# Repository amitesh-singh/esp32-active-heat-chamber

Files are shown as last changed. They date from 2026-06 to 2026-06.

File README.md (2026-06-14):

# ESP32 Active Heat Chamber

An ESP32-C3-based active heat chamber controller for 3D printers, designed to integrate with [Klipper](https://www.klipper3d.org/) via a REST API. It drives a PTC ceramic heater and a 5015 blower fan using closed-loop PID temperature control, and exposes an HTTP API that Klipper macros call directly via `gcode_shell_command`.

## Table of Contents

- [Features](#features)
- [Hardware](#hardware)
  - [Schematic](#schematic)
  - [Assembly](#assembly)
  - [Bill of Materials](#bill-of-materials)
  - [Pin Assignments](#pin-assignments)
- [Software Architecture](#software-architecture)
- [Dependencies](#dependencies)
- [Getting Started](#getting-started)
  - [Compile](#compile)
  - [Upload via USB](#upload-via-usb)
  - [OTA Updates](#ota-updates)
- [Configuration](#configuration)
- [REST API](#rest-api)
- [Klipper Integration](#klipper-integration) *(work in progress)*
- [License](#license)

---

## Features

- **PID temperature control** — closed-loop heater control with anti-windup
- **Time-proportional heater output** — SSR-compatible PWM-style on/off cycling (2 s cycle)
- **5015 blower fan control** — 25 kHz PWM via ESP32-C3 LEDC peripheral
- **SHT30 temperature + humidity sensor** — high-accuracy I²C sensor
- **OLED status display** — 128×64 SSD1306 showing temp, humidity, setpoint, fan, and PID power bar
- **HTTP REST API** — control heater, fan, and setpoint from any client
- **Klipper integration** *(work in progress)* — `klipper_chamber.cfg` with GCode macros
- **Automatic OTA firmware updates** — checks a self-hosted HTTPS server on boot and updates if a newer version is available
- **WiFiManager captive portal** — no hardcoded credentials; connect to the `HeaterChamber-XXXX` AP on first boot to configure WiFi
- **MCU temperature monitoring** — uses the ESP32-C3 internal temperature sensor
- **Safety limits** — hard cut-off at 65 °C and automatic recovery when temperature overshoots setpoint by ≥ 5 °C

---

## Hardware

### Schematic

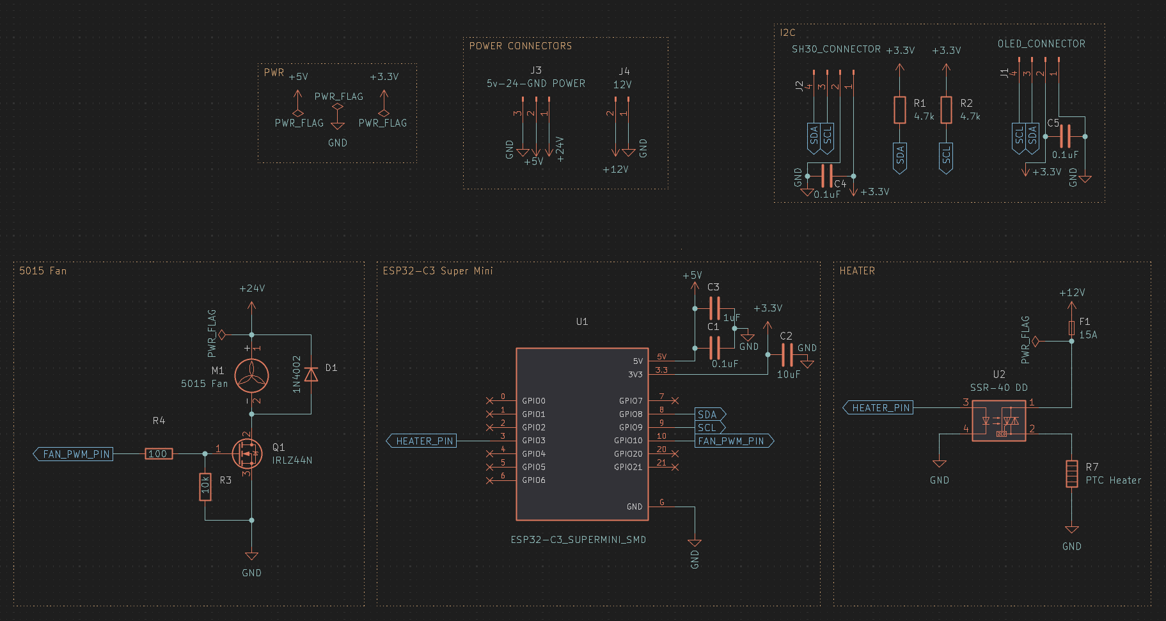
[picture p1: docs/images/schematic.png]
Schematic


> Place the exported schematic PNG at `docs/images/schematic.png`.

The circuit consists of four blocks:

| Block | Description |
|---|---|
| **ESP32-C3 Super Mini** | Main MCU — runs the HTTP server, PID loop, and OTA |
| **Heater driver** | SSR-40 DD solid-state relay switches 12 V to the PTC heater through a 15 A fuse |
| **Fan driver** | IRLZ44N logic-level MOSFET with 100 Ω gate resistor and 10 kΩ pull-down drives the 24 V 5015 fan |
| **I²C peripherals** | SHT30 sensor and SSD1306 OLED share the I²C bus with 4.7 kΩ pull-ups |

### Assembly

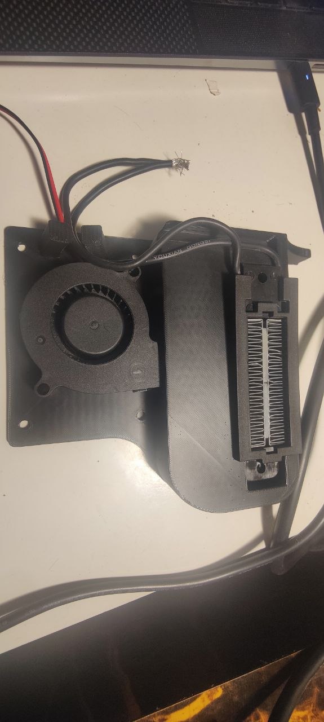
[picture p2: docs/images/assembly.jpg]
Assembly — blower fan and PTC heater holder


> Place the assembly photo at `docs/images/assembly.jpg`.

The 3D-printed mount (STL/STEP files in `enclosures/fan-ptcheater-holder/`) integrates a **5015 radial blower fan** and a **PTC ceramic heater** side-by-side. Airflow is forced through the PTC element and into the printer enclosure.

---

### Bill of Materials

| # | Component | Value / Part | Qty | Notes |
|---|---|---|---|---|
| U1 | ESP32-C3 Super Mini | — | 1 | SMD or through-hole module |
| U2 | Solid-state relay | SSR-40 DD | 1 | 12 V load side, 3.3 V control |
| Q1 | N-channel MOSFET | IRLZ44N | 1 | Logic-level gate, TO-220 |
| M1 | Blower fan | 5015, 24 V | 1 | ~1.5 A rated |
| — | PTC ceramic heater | 12 V, ~100 W | 1 | R7 in schematic |
| F1 | Fuse | 15 A | 1 | Inline on 12 V rail |
| D1 | Flyback diode | 1N4002 | 1 | Across fan motor |
| R1, R2 | I²C pull-up | 4.7 kΩ | 2 | SDA/SCL lines |
| R3 | Gate pull-down | 10 kΩ | 1 | MOSFET gate |
| R4 | Gate resistor | 100 Ω | 1 | MOSFET gate series |
| C1 | Bulk cap | 1 µF | 1 | 5 V rail |
| C2 | Bypass cap | 10 µF | 1 | 3.3 V rail |
| C3 | Bypass cap | 0.1 µF | 1 | 5 V rail |
| C4 | Bypass cap | 0.1 µF | 1 | SHT30 VDD |
| C5 | Bypass cap | 0.1 µF | 1 | OLED VDD |
| J2 | SHT30 connector | 4-pin SH1.0 | 1 | VDD, GND, SDA, SCL |
| J1 | OLED connector | 4-pin | 1 | VCC, GND, SCL, SDA |
| J3 | Power connector | 3-pin (5 V, 24 V, GND) | 1 | — |
| J4 | Power connector | 2-pin (12 V, GND) | 1 | — |
| — | SHT30 sensor module | — | 1 | I²C address 0x44 |
| — | SSD1306 OLED | 128×64 | 1 | I²C address 0x3C |

### Pin Assignments

| GPIO | Function |
|---|---|
| GPIO 3 | Heater SSR control (on/off) |
| GPIO 10 | Fan PWM (25 kHz LEDC) |
| GPIO 8 | I²C SDA (SHT30 + OLED) |
| GPIO 9 | I²C SCL (SHT30 + OLED) |

---

## Software Architecture

```
active_heat_chamber_esp32.ino   Main sketch: WiFi, HTTP server, sensor loop, PID loop
config.h                        Compile-time constants (pins, PID gains, safety limits)
heater_controller.h             Time-proportional on/off heater class
pid_controller.h                Generic PID with anti-windup and output clamping
oled_display.h                  SSD1306 status display
automatic_ota.h                 HTTPS OTA update client
```

The main loop runs three independent timed tasks:

| Task | Interval | Action |
|---|---|---|
| Sensor read | 1 s | Read SHT30 temp + humidity, run safety checks |
| PID update | 500 ms | Compute PID output, apply to `heater_controller` and fan |
| OLED refresh | 1 s | Redraw display |

---

## Dependencies

Install these via the Arduino Library Manager or `arduino-cli lib install`:

| Library | Purpose |
|---|---|
| `WiFiManager` | Captive-portal WiFi provisioning |
| `Adafruit GFX Library` | OLED graphics primitives |
| `Adafruit SSD1306` | SSD1306 OLED driver |
| `SensirionI2cSht3x` | SHT30/SHT31 sensor driver |
| `ArduinoJson` | JSON parsing for OTA manifest |
| `ElegantOTA` *(optional)* | Web-based OTA (disabled by default — uncomment `#define WEB_OTA`) |

Board package: **esp32 by Espressif** — install via Board Manager (`https://raw.githubusercontent.com/espressif/arduino-esp32/gh-pages/package_esp32_index.json`).

---

## Getting Started

### Compile

```bash
./build.sh
```

This calls `arduino-cli` targeting the **ESP32-C3** with CDC-on-boot enabled and the `min_spiffs` partition scheme:

```bash
arduino-cli compile -v \
  --fqbn esp32:esp32:esp32c3:CDCOnBoot=cdc,PartitionScheme=min_spiffs \
  --build-property "compiler.optimization_flags=-Os" \
  .
```

### Upload via USB

Connect the ESP32-C3 Super Mini over USB, then:

```bash
./upload.sh
```

This runs:

```bash
arduino-cli upload \
  -p /dev/ttyACM0 \
  --fqbn esp32:esp32:esp32c3:CDCOnBoot=cdc,PartitionScheme=min_spiffs \
  .
```

> Adjust the port (`-p /dev/ttyACM0`) if your device appears on a different path (e.g. `/dev/ttyUSB0`).

### OTA Updates

Firmware updates are served over HTTPS from a local server. The ESP32 checks `UPDATE_JSON_URL` (defined in `active_heat_chamber_esp32.ino`) on every boot.

#### 1. Generate TLS certificates

```bash
cd ota_server
./create_keys.sh   # creates cert.pem and key.pem (self-signed, valid 365 days)
```

#### 2. Build and package firmware

```bash
./build.sh         # compile the sketch
./flash.sh         # copies the .bin to ota_server/firmware.bin and writes firmware.json
```

`flash.sh` reads `FW_VERSION` from `config.h` and generates:

```json
{
  "version": "0.1.1",
  "firmware": "https://192.168.1.13/firmware.bin"
}
```

#### 3. Start the HTTPS server

```bash
cd ota_server
sudo python3 https_run.py   # serves on port 443
```

> For plain HTTP testing on port 80: `./http_run.sh`

Update `UPDATE_JSON_URL` in `active_heat_chamber_esp32.ino` to point at your server's IP.

---

## Configuration

All compile-time settings live in `config.h`:

```cpp
#define FW_VERSION       "0.1.1"

// GPIO
#define HEATER_PIN       3      // SSR control
#define FAN_PWM_PIN      10     // LEDC PWM output

// Fan PWM
#define FAN_FREQ_HZ      25000  // 25 kHz
#define FAN_RESOLUTION   8      // 0–255

// Safety
#define MAX_TEMP_C       65.0f  // Hard cut-off temperature
#define DEFAULT_TARGET   50.0f  // Default setpoint on boot
#define HEATER_CYCLE_MS  2000   // Time-proportional cycle period (ms)

// PID gains
#define PID_KP           0.08f
#define PID_KI           0.015f
#define PID_KD           0.005f

// I²C
#define I2C_SDA          8
#define I2C_SCL          9
```

Tune `PID_KP`, `PID_KI`, `PID_KD` to match your heater and fan combination.

---

## REST API

The HTTP server listens on port **80**. All responses are JSON.

| Method | Endpoint | Parameters | Description |
|---|---|---|---|
| `GET` | `/status` | — | Returns full chamber status |
| `POST` | `/heater` | `state=on\|off` | Enable or disable the heater |
| `POST` | `/temp` | `target=<20–80>` | Set target temperature (°C) |
| `POST` | `/fan` | `speed=<0–255>` | Override fan speed |

### `/status` response

```json
{
  "temp": 47.32,
  "humid": 28.10,
  "setpoint": 50.0,
  "heater": true,
  "fan": 180,
  "pid_output": 0.612,
  "safety_tripped": false,
  "sensor_fault": false,
  "mcu_temp": 38.50,
  "fw_ver": "0.1.1",
  "ip": "192.168.1.20"
}
```

### Examples

```bash
# Turn heater on
curl -X POST "http://192.168.1.20/heater?state=on"

# Set target to 60 °C
curl -X POST "http://192.168.1.20/temp?target=60"

# Set fan to 50 % (128/255)
curl -X POST "http://192.168.1.20/fan?speed=128"

# Read status
curl "http://192.168.1.20/status"
```

### Web UI

The ESP32 also serves a built-in web dashboard at `http://<ESP32_IP>/`. It auto-refreshes every second and provides full control without any external tooling.

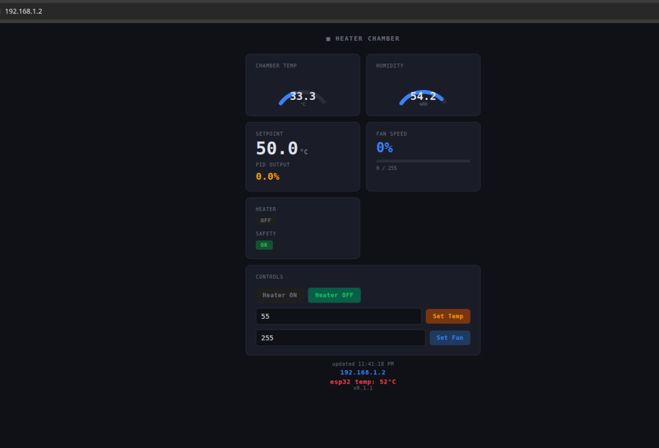
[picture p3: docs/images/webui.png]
Web UI — Heater Chamber dashboard


> Place the web UI screenshot at `docs/images/webui.png`.

The dashboard shows:
- **Chamber Temp** and **Humidity** gauges
- **Setpoint** and current **PID output**
- **Fan speed** bar and value
- **Heater** state (ON/OFF) and **Safety** status
- Controls to toggle the heater, set target temperature, and set fan speed
- Footer showing last-update time, IP address, MCU temperature, and firmware version

---

## Klipper Integration

> **Work in progress** — the Klipper integration (`klipper_chamber.cfg` and `chamber_control.sh`) is functional but still being refined. Use the [REST API](#rest-api) or the [Web UI](#web-ui) for direct control in the meantime.

### 1. Install the `gcode_shell_command` plugin

```bash
cd ~/klipper
wget -O klippy/extras/gcode_shell_command.py \
  https://raw.githubusercontent.com/th33xitus/kiauh/master/resources/gcode_shell_command.py
```

### 2. Install the control script

```bash
sudo cp chamber_control.sh /usr/local/bin/chamber_control.sh
sudo chmod +x /usr/local/bin/chamber_control.sh
```

Edit `ESP32_IP` at the top of `chamber_control.sh` to match your ESP32's IP address (assign a static DHCP lease in your router for reliability).

### 3. Include the config

Add to `printer.cfg`:

```ini
[include klipper_chamber.cfg]
```

### Available GCode macros

| Macro | Example | Description |
|---|---|---|
| `CHAMBER_ON` | `CHAMBER_ON TEMP=60` | Enable heater and set target temperature |
| `CHAMBER_OFF` | `CHAMBER_OFF` | Disable heater and fan |
| `CHAMBER_TEMP` | `CHAMBER_TEMP TARGET=65` | Change setpoint while running |
| `CHAMBER_FAN` | `CHAMBER_FAN SPEED=180` | Set fan speed (0–255) |
| `CHAMBER_STATUS` | `CHAMBER_STATUS` | Print current status to console |
| `CHAMBER_WAIT` | `CHAMBER_WAIT TEMP=58` | Block until chamber reaches temperature |

### Typical print-start sequence

```gcode
CHAMBER_ON TEMP=60          ; start heating
CHAMBER_WAIT TEMP=55        ; wait until warm enough
; ... home, load filament, start print ...
CHAMBER_OFF                 ; cool down after print
```

---

## License

[LICENSE](LICENSE)

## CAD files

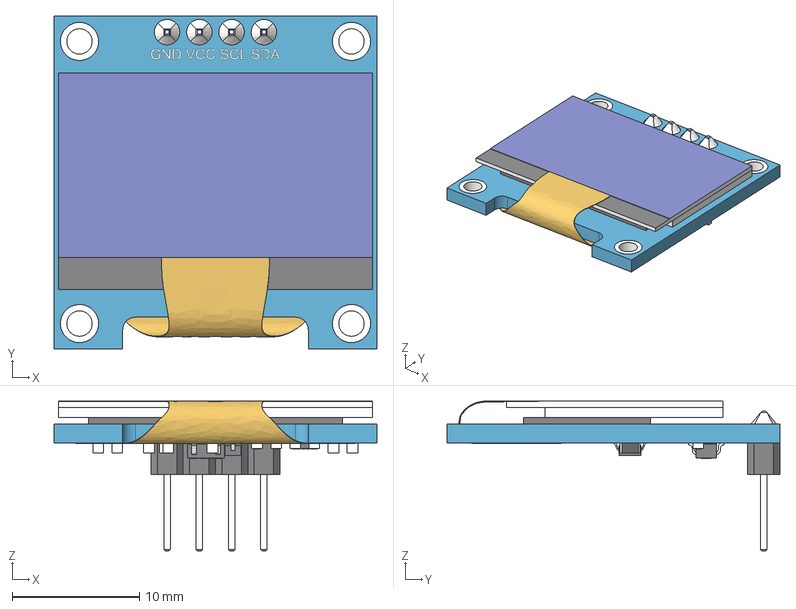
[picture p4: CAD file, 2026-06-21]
enclosures/esp32c3-oled/SSD1306_OLED_Display(128x64).step
25.4 x 26.2 x 11.8 mm
board
screen
pin_header
soldering
smd_capacitor
smd_capacitor (1)
914_smd_resistor
472_smd_resistor x 3
t4_smd_diode
smd_capacitor (2)
smd_capacitor (3)
smd_capacitor (4)
smd_capacitor (5)
smd_capacitor (6)
472_smd_resistor (1)
SOT-23_XC6206 v3
smd_capacitor (7)
flat_cable

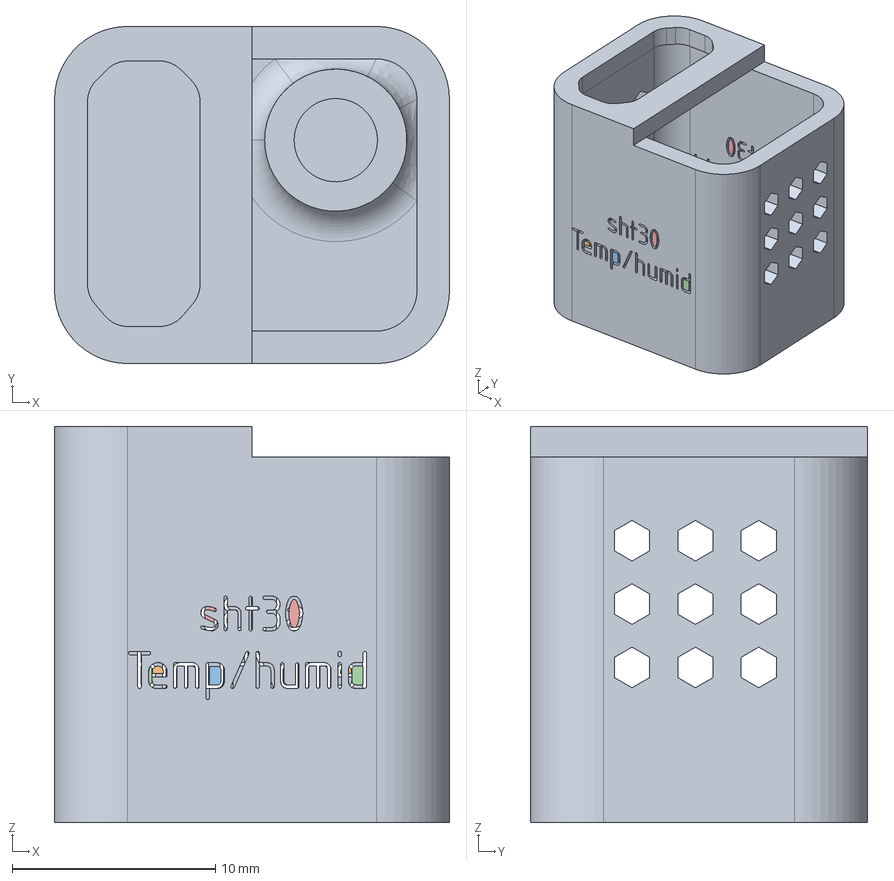
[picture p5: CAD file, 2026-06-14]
enclosures/sht30/sht30-sht30cover.step
19.5 x 16.6 x 19.5 mm

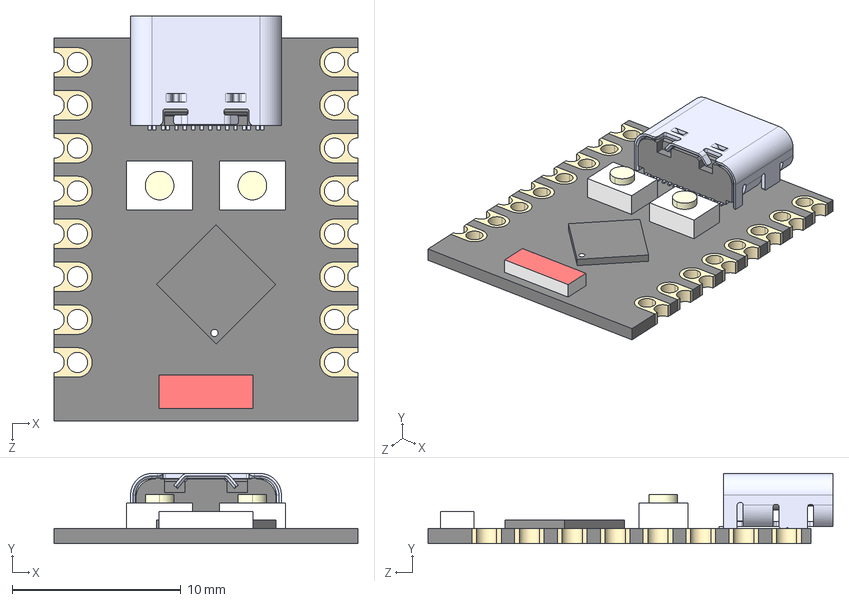
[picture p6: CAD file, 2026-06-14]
schematics/heater/ESP32-C3_SUPERMINI_SMD.step
18.0 x 4.16 x 24.0 mm
Board c3mini
USB C
components (other)^ESP32-C3 SuperMini

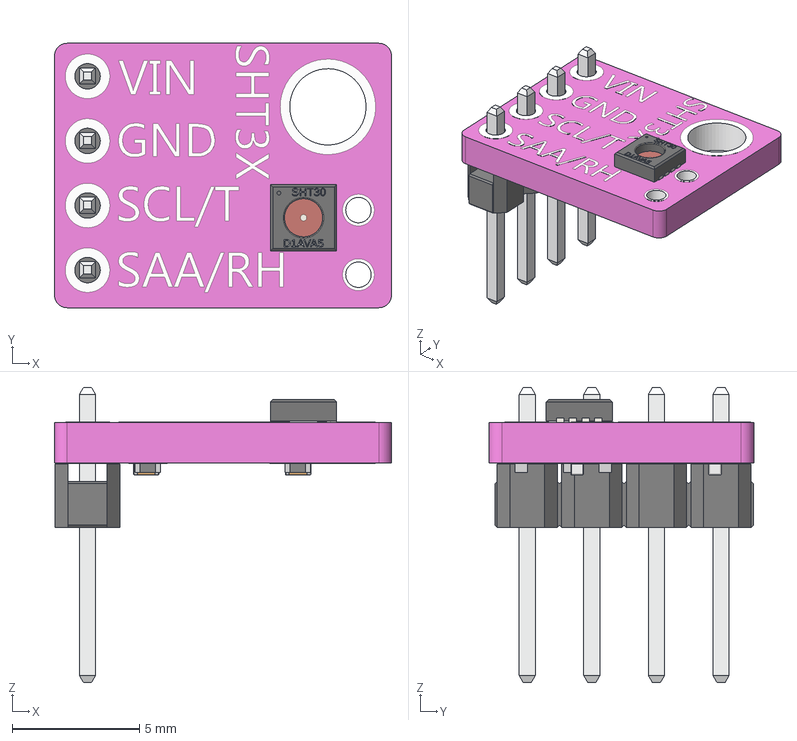
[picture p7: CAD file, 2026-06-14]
enclosures/sht30/SHT30-Purple Straight Pins.step
13.2 x 10.4 x 11.6 mm
PCB
Resistor 0402 x 3
pin x 4

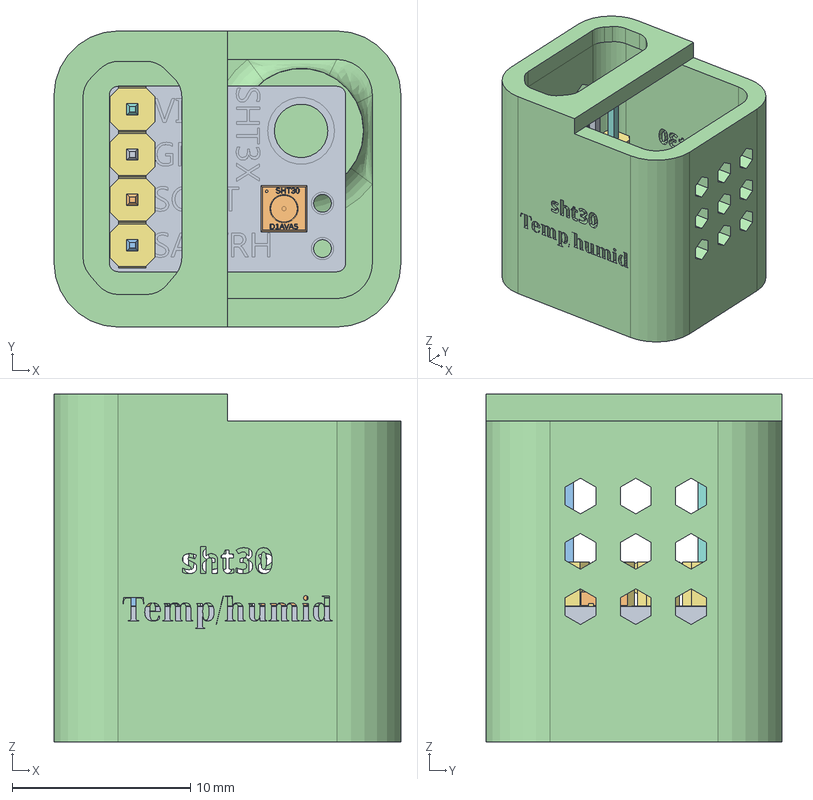
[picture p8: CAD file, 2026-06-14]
enclosures/sht30/sht30.FCStd
19.5 x 16.6 x 19.5 mm
PCB
Resistor 0402 v2
Resistor 0402 v001
Resistor 0402 v002
Resistor 0402 v003
Resistor 0402 v004
Resistor 0402 v005
Resistor 0402 v006
Resistor 0402 v008
Resistor 0402 v009
Resistor 0402 v010
Resistor 0402 v011
Resistor 0402 v012
Resistor 0402 v013
Resistor 0402 v014
Resistor 0402 v016
Resistor 0402 v017
Resistor 0402 v018
Resistor 0402 v019
Resistor 0402 v020
Resistor 0402 v021
Resistor 0402 v022
pin
pin001
pin002
pin003
sht30cover

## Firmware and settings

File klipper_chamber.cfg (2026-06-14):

# klipper_chamber.cfg
# Heater chamber control via gcode_shell_command → ESP32 REST API
#
# Prerequisites:
#   1. Install gcode_shell_command plugin:
#      cd ~/klipper
#      wget -O ~/klipper/klippy/extras/gcode_shell_command.py \
#        https://raw.githubusercontent.com/th33xitus/kiauh/master/resources/gcode_shell_command.py
#
#   2. Install and configure the shell script:
#      sudo cp chamber_control.sh /usr/local/bin/chamber_control.sh
#      sudo chmod +x /usr/local/bin/chamber_control.sh
#      # Edit ESP32_IP in the script to match your ESP32's IP
#
#   3. Include this file in printer.cfg:
#      [include klipper_chamber.cfg]
#
# Usage in GCode / macros:
#   CHAMBER_ON TEMP=60
#   CHAMBER_OFF
#   CHAMBER_TEMP TARGET=65
#   CHAMBER_FAN SPEED=180
#   CHAMBER_STATUS
#   CHAMBER_WAIT TEMP=58        ; blocks until chamber reaches temp


# ── Shell command definitions ─────────────────────────────────────────────────

[gcode_shell_command chamber_heater_on]
command: /usr/local/bin/chamber_control.sh heater on
timeout: 8
verbose: True

[gcode_shell_command chamber_heater_off]
command: /usr/local/bin/chamber_control.sh heater off
timeout: 8
verbose: True

[gcode_shell_command chamber_set_temp]
command: /usr/local/bin/chamber_control.sh temp
timeout: 8
verbose: True

[gcode_shell_command chamber_set_fan]
command: /usr/local/bin/chamber_control.sh fan
timeout: 8
verbose: True

[gcode_shell_command chamber_get_status]
command: /usr/local/bin/chamber_control.sh status
timeout: 8
verbose: True


# ── GCode Macros ──────────────────────────────────────────────────────────────

# CHAMBER_ON TEMP=60
# Turn heater on and set target temperature (default 60°C)
[gcode_macro CHAMBER_ON]
description: Turn on heater chamber and set target temperature
gcode:
    {% set target = params.TEMP|default(60)|float %}
    M118 Chamber: setting target to {target}C
    RUN_SHELL_COMMAND CMD=chamber_set_temp PARAMS="{target}"
    RUN_SHELL_COMMAND CMD=chamber_heater_on
    M118 Chamber: heater ON, target={target}C


# CHAMBER_OFF
# Turn off heater and fan
[gcode_macro CHAMBER_OFF]
description: Turn off heater chamber
gcode:
    M118 Chamber: turning off
    RUN_SHELL_COMMAND CMD=chamber_heater_off
    M118 Chamber: heater OFF


# CHAMBER_TEMP TARGET=65
# Update setpoint without toggling heater state
[gcode_macro CHAMBER_TEMP]
description: Set chamber target temperature
gcode:
    {% set target = params.TARGET|default(60)|float %}
    M118 Chamber: setpoint → {target}C
    RUN_SHELL_COMMAND CMD=chamber_set_temp PARAMS="{target}"


# CHAMBER_FAN SPEED=180
# Manually override fan speed (0-255). Heater auto-fan resumes on next PID cycle.
[gcode_macro CHAMBER_FAN]
description: Set chamber fan speed (0-255)
gcode:
    {% set speed = params.SPEED|default(128)|int %}
    M118 Chamber: fan → {speed}
    RUN_SHELL_COMMAND CMD=chamber_set_fan PARAMS="{speed}"


# CHAMBER_STATUS
# Print current chamber state to console
[gcode_macro CHAMBER_STATUS]
description: Query chamber temperature and state
gcode:
    M118 Chamber: querying status...
    RUN_SHELL_COMMAND CMD=chamber_get_status


# CHAMBER_WAIT TEMP=58
# Poll chamber until temperature reaches target (blocking, with timeout)
# Call BEFORE starting a print that needs a warm chamber.
[gcode_macro CHAMBER_WAIT]
description: Wait for chamber to reach target temperature
variable_poll_interval: 10    ; seconds between status checks
variable_max_wait: 1200       ; max wait time in seconds (20 min)
gcode:
    {% set target = params.TEMP|default(55)|float %}
    {% set tolerance = params.TOLERANCE|default(2)|float %}
    M118 Chamber: waiting for {target}C (±{tolerance}C)...
    RUN_SHELL_COMMAND CMD=chamber_set_temp PARAMS="{target}"
    RUN_SHELL_COMMAND CMD=chamber_heater_on

    # Klipper's TEMPERATURE_WAIT can't query external sensors directly,
    # so we use a timed loop with shell status checks.
    # For a cleaner approach, expose the ESP32 temp as a dummy sensor (see note below).
    {% set ns = namespace(elapsed=0, done=false) %}
    {% for i in range((max_wait // poll_interval)|int) %}
        {% if not ns.done %}
            G4 P{poll_interval * 1000}
            RUN_SHELL_COMMAND CMD=chamber_get_status
            M118 Chamber: waiting... ({(i+1)*poll_interval}s elapsed)
        {% endif %}
    {% endfor %}
    M118 Chamber: wait complete (or timed out after {max_wait}s)

# ── Print start / end integration ─────────────────────────────────────────────
# Add these calls to your existing START_PRINT / END_PRINT macros:
#
# [gcode_macro START_PRINT]
# gcode:
#     ...
#     CHAMBER_ON TEMP=60          # start heating
#     CHAMBER_WAIT TEMP=58        # wait before printing (optional)
#     ...
#
# [gcode_macro END_PRINT]
# gcode:
#     ...
#     CHAMBER_OFF                 # cut heater when done
#     ...
#
# ── Expose ESP32 temp as a Klipper sensor (optional but recommended) ──────────
# This lets TEMPERATURE_WAIT and the Mainsail/Fluidd dashboard see chamber temp.
# Requires a small Python sensor plugin or moonraker data_store — see:
# https://www.klipper3d.org/Config_Reference.html#temperature_sensor
#
# [temperature_sensor chamber]
# sensor_type: temperature_host   # placeholder; replace with custom plugin

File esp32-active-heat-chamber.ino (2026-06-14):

/**
 * chamber_server.ino
 * ESP32 HTTP REST server for Klipper-controlled heater chamber
 *
 * Endpoints:
 *   POST /heater?state=on|off
 *   POST /temp?target=50.0
 *   POST /fan?speed=0-255
 *   GET  /status   → JSON: temp, humid, setpoint, heater, fan, pid_output, safety_tripped, sensor_fault, mcu_temp, fw_ver, ip
 *
 */

#include <Arduino.h>
#include <WiFi.h>
#include <WebServer.h>
#include <Wire.h>
#include <WiFiManager.h>

#include "config.h"
#include "heater_controller.h"
#include "pid_controller.h"

#define DEBUG
//#define WEB_OTA
#ifdef WEB_OTA
#include <ElegantOTA.h>
#endif 

#include "oled_display.h"
display *d = nullptr;

#include "automatic_ota.h"

#include <SensirionI2cSht3x.h>
SensirionI2cSht3x sht30;

// ESP-IDF temperature sensor API
extern "C" {
  #include "driver/temperature_sensor.h"
}
temperature_sensor_handle_t temp_sensor = NULL;

void setup_mcu_temp()
{
  temperature_sensor_config_t temp_config = {
    .range_min = -10,  // Minimum expected temperature (°C)
    .range_max = 80    // Maximum expected temperature (°C)
  };

  // Install temperature sensor
  esp_err_t err = temperature_sensor_install(&temp_config, &temp_sensor);
  if (err != ESP_OK) {
    #ifdef DEBUG
    Serial.println("Failed to install temperature sensor");
    #endif
    return;
  }

  // Enable temperature sensor
  err = temperature_sensor_enable(temp_sensor);
  if (err != ESP_OK) {
    #ifdef DEBUG
    Serial.println("Failed to enable temperature sensor");
    #endif
    return;
  }
  #ifdef DEBUG
  Serial.println("Temperature sensor initialized\n");
  #endif
}

heater_controller  hc(HEATER_PIN, HEATER_CYCLE_MS);
pid_controller pid(PID_KP, PID_KI, PID_KD, 0.0f, 1.0f);
WebServer     server(80);
#ifdef WEB_OTA
WebServer ota_server(81);
#endif

//TODO: change it to github later
#define UPDATE_JSON_URL "https://192.168.1.13/firmware.json"

https_ota ota(
    FW_VERSION,
    UPDATE_JSON_URL,
    []() { if (d) d->ota_update_uptodate(); },
    []() { if (d) d->ota_update_install(); }
);

float   currentTemp     = 0.0f;
float   currentHumidity = 0.0f;
float   pidOutput     = 0.0f;
uint8_t fanSpeed      = 0;
bool    heaterEnabled = false;
bool    safetyTripped = false;
bool    sensorOk        = false;
bool    sensorFault     = false;
bool    highTempFault   = false;
bool    forceHeaterStopped = false;
float   mcu_temp = 0.0f;

uint32_t lastPid    = 0;
uint32_t lastSensor = 0;
uint32_t lastOled    = 0;

constexpr const auto HTTP_RESPONSE_200 = 200;
constexpr const auto HTTP_RESPONSE_400 = 400;

bool readSensor()
{
    float t, h;
    uint16_t err = sht30.measureSingleShot(REPEATABILITY_HIGH, false, t, h);
    if (err) {
      #ifdef DEBUG
        Serial.printf("[SHT30] Error: %d\r\n", err);
      #endif  
        sensorFault = true;
        return false;
    }
    sensorFault = false;
    currentTemp     = t;
    currentHumidity = h;
    return true;
}

void applyFanSpeed(uint8_t speed)
{
    fanSpeed = speed;
    ledcWrite(FAN_PWM_PIN, speed);
}

void checkSafety(float t)
{
    if (t >= MAX_TEMP_C || t < -50.0f) {
        hc.emergencyStop();
        applyFanSpeed(255);
        heaterEnabled = false;
        safetyTripped = true;
        #ifdef DEBUG
        Serial.printf("[SAFETY] Tripped at %.1f°C\n", t);
        #endif

    } else {
      //The currentTemp should not go more than 5C than the setTemp
      if (heaterEnabled and currentTemp > pid.getSetpoint() and (currentTemp - pid.getSetpoint()) >= 5) {
        applyFanSpeed(0);
        hc.emergencyStop();
        heaterEnabled = false;
        highTempFault = true;
        
        safetyTripped = true;
        #ifdef DEBUG
        Serial.printf("[SAFETY] currentTemp is higher than setTemp: %.2f : %.2f\r\n",
          currentTemp, pid.getSetpoint());
        #endif 
      }
    }

    if (sensorFault)  {
      hc.emergencyStop();
      applyFanSpeed(0);
      heaterEnabled = false;
      safetyTripped = true;
      #ifdef DEBUG
      Serial.println("[SAFETY] Tripped due to sensor fault");
      #endif
    } else {
      //if the sensor is ok, we can clear the fault;
      //heaterEnabled = true;
      if (!highTempFault)
        safetyTripped = false;
    }
    
    //only clear the fault if externally heater is not stopped
    if (!forceHeaterStopped and highTempFault) {
      //wait for the currentTemp to go down; to restart everything.
      if (currentTemp < pid.getSetpoint() and (pid.getSetpoint() - currentTemp) >= 2) {
        //clear the fault;
        heaterEnabled = true;
        hc.enable();
        pid.reset();
        highTempFault = false;
        safetyTripped = false;
        #ifdef DEBUG
        Serial.printf("[SAFETY] cleared the fault:\r\n");
        #endif
      }
    }
}

String statusJson()
{
    char buf[256];
    String ip = WiFi.localIP().toString();
    constexpr auto *t = "true";
    constexpr auto *f = "false";

    snprintf(buf, sizeof(buf),
        "{\"temp\":%.2f,\"humid\":%.2f,\"setpoint\":%.1f,\"heater\":%s,"
        "\"fan\":%d,\"pid_output\":%.3f,\"safety_tripped\":%s,"
        "\"sensor_fault\":%s,"
        "\"mcu_temp\":%.2f,"
        "\"fw_ver\":\"%s\","
        "\"ip\":\"%s\"}",
        currentTemp, currentHumidity, pid.getSetpoint(),
        heaterEnabled ? t : f,
        fanSpeed, pidOutput,
        safetyTripped ? t : f,
        sensorFault ? t : f,
        mcu_temp,
        FW_VERSION,
        ip.c_str());

    return String(buf);
}

// GET /status
void handleStatus()
{
    server.send(HTTP_RESPONSE_200, "application/json", statusJson());
}

// POST /heater?state=on|off
void handleHeater()
{
    if (!server.hasArg("state")) {
        server.send(HTTP_RESPONSE_400, "application/json", "{\"error\":\"missing state\"}"); return;
    }
    String state = server.arg("state");
    if (state == "on" && !safetyTripped) {
        forceHeaterStopped = false;
        heaterEnabled = true;
        hc.enable();
        pid.reset();
        #ifdef DEBUG
        Serial.println("[HTTP] Heater ON");
        #endif
    } else if (state == "off") {
        forceHeaterStopped = true;
        heaterEnabled = false;
        //we clear the hightemp fault too;
        highTempFault = false;
        safetyTripped = false;
        hc.disable();
        applyFanSpeed(0);
        pidOutput = 0;
        pid.reset();
        #ifdef DEBUG
        Serial.println("[HTTP] Heater OFF");
        #endif
    } else {
        server.send(HTTP_RESPONSE_400, "application/json", "{\"error\":\"invalid state\"}"); return;
    }
    server.send(HTTP_RESPONSE_200, "application/json", statusJson());
}

// POST /temp?target=50.0
void handleTemp() 
{
    if (!server.hasArg("target")) {
        server.send(HTTP_RESPONSE_400, "application/json", "{\"error\":\"missing target\"}"); return;
    }
    float target = server.arg("target").toFloat();
    if (target < 20.0f || target > 80.0f) {
        server.send(HTTP_RESPONSE_400, "application/json", "{\"error\":\"range 20-80C\"}"); return;
    }
    pid.setSetpoint(target);
    pid.reset();
    #ifdef DEBUG
    Serial.printf("[HTTP] Setpoint → %.1f°C\n", target);
    #endif
    server.send(HTTP_RESPONSE_200, "application/json", statusJson());
}

// POST /fan?speed=0-255
static void handleFan()
{
    if (!server.hasArg("speed")) {
        server.send(HTTP_RESPONSE_400, "application/json", "{\"error\":\"missing speed\"}"); return;
    }
    int speed = constrain(server.arg("speed").toInt(), 0, 255);
    applyFanSpeed((uint8_t)speed);
    #ifdef DEBUG
    Serial.printf("[HTTP] Fan → %d\n", speed);
    #endif
    server.send(HTTP_RESPONSE_200, "application/json", statusJson());
}

static void setupWifi()
{
  WiFi.mode(WIFI_STA);
  // Get the unique chip ID (48-bit MAC)
  uint64_t chipid = ESP.getEfuseMac();

  // Format it into a readable hex string
  char ssid[40];
  sprintf(ssid, "HeaterChamber-%04X", (uint16_t)(chipid & 0xFFFF));

  // Initialize WiFiManager with custom SSID
  WiFiManager wifi_manager;
  wifi_manager.autoConnect(ssid);

  #ifdef DEBUG
  Serial.printf("\n[WIFI] IP: %s\n", WiFi.localIP().toString().c_str());
  Serial.print("Access Point SSID: ");
  Serial.println(ssid);
  #endif
}

// ── Setup ─────────────────────────────────────────────────────────────────────
void setup() 
{  
  #ifdef DEBUG
  Serial.begin(115200);
  delay(100);
  #endif
  
  hc.begin();
  hc.disable();
  pid.setSetpoint(DEFAULT_TARGET);

  setup_mcu_temp();

  ledcAttach(FAN_PWM_PIN, FAN_FREQ_HZ, FAN_RESOLUTION);
  applyFanSpeed(0);


  //analogSetAttenuation(ADC_11db);
  //analogReadResolution(12);

  setupWifi();
  
  // SHT30
  Wire.begin();
  delay(50);
  sht30.begin(Wire, SHT30_I2C_ADDR_44);

  d = new display();
  d->begin();
  d->ota_update();
  ota.checkAndUpdate();

  server.on("/", HTTP_GET, []() {
  server.send(HTTP_RESPONSE_200, "text/html", R"rawhtml(
<!DOCTYPE html>
<html lang="en">
<head>
<meta charset="UTF-8">
<meta name="viewport" content="width=device-width, initial-scale=1">
<title>Heater Chamber</title>
<style>
  :root {
    --bg:       #0f1117;
    --surface:  #1a1d27;
    --border:   #2a2d3a;
    --text:     #e2e4ed;
    --muted:    #6b7080;
    --accent:   #f59e0b;
    --red:      #ef4444;
    --green:    #22c55e;
    --blue:     #3b82f6;
  }
  * { box-sizing: border-box; margin: 0; padding: 0; }
  body {
    background: var(--bg);
    color: var(--text);
    font-family: ui-monospace, 'Cascadia Code', monospace;
    min-height: 100vh;
    display: flex;
    flex-direction: column;
    align-items: center;
    padding: 24px 16px;
  }
  h1 {
    font-size: 13px;
    letter-spacing: .12em;
    text-transform: uppercase;
    color: var(--muted);
    margin-bottom: 24px;
  }
  .grid {
    display: grid;
    grid-template-columns: repeat(2, 1fr);
    gap: 12px;
    width: 100%;
    max-width: 480px;
  }
  .card {
    background: var(--surface);
    border: 1px solid var(--border);
    border-radius: 10px;
    padding: 18px 20px;
  }
  .card.wide { grid-column: 1 / -1; }
  .label {
    font-size: 10px;
    letter-spacing: .1em;
    text-transform: uppercase;
    color: var(--muted);
    margin-bottom: 6px;
  }
  .value {
    font-size: 36px;
    font-weight: 600;
    line-height: 1;
    color: var(--text);
  }
  .value.hot  { color: var(--accent); }
  .value.cool { color: var(--blue); }
  .unit {
    font-size: 14px;
    color: var(--muted);
    margin-left: 3px;
  }
  .badge {
    display: inline-block;
    padding: 3px 10px;
    border-radius: 4px;
    font-size: 11px;
    font-weight: 600;
    letter-spacing: .06em;
    text-transform: uppercase;
    white-space: normal;
    word-break: break-word;
    max-width: 100%;
  }
  .badge.on  { background: #14532d; color: var(--green); }
  .badge.off { background: #1f1f1f; color: var(--muted); }
  .badge.warn { background: #450a0a; color: var(--red); }

  /* Arc gauge */
  .gauge-wrap {
    display: flex;
    flex-direction: column;
    align-items: center;
    gap: 6px;
  }
  .arc-svg { overflow: visible; }
  .arc-track { fill: none; stroke: var(--border); stroke-width: 8; }
  .arc-fill  { fill: none; stroke-width: 8; stroke-linecap: round;
               transition: stroke-dashoffset .6s ease, stroke .4s; }
  .arc-text  { font-family: inherit; font-weight: 600; fill: var(--text); }
  .arc-sub   { font-family: inherit; fill: var(--muted); }

  /* Fan bar */
  .fan-bar-wrap { margin-top: 8px; }
  .fan-bar-bg {
    height: 6px;
    background: var(--border);
    border-radius: 3px;
    overflow: hidden;
    margin-top: 8px;
  }
  .fan-bar-fill {
    height: 100%;
    background: var(--blue);
    border-radius: 3px;
    transition: width .5s ease;
  }
  .fan-pct { font-size: 28px; font-weight: 600; color: var(--blue); }

  /* Controls */
  .controls { display: flex; flex-direction: column; gap: 10px; }
  .row { display: flex; gap: 8px; align-items: center; }
  input[type=number] {
    flex: 1;
    background: var(--bg);
    border: 1px solid var(--border);
    border-radius: 6px;
    color: var(--text);
    font-family: inherit;
    font-size: 14px;
    padding: 8px 10px;
    outline: none;
  }
  input[type=number]:focus { border-color: var(--accent); }
  button {
    padding: 8px 14px;
    border: none;
    border-radius: 6px;
    font-family: inherit;
    font-size: 12px;
    font-weight: 600;
    letter-spacing: .05em;
    cursor: pointer;
    transition: opacity .15s;
  }
  button:hover { opacity: .85; }
  button:active { opacity: .7; }
  .btn-on  { background: #065f46; color: var(--green); }
  .btn-off { background: #1f1f1f; color: var(--muted); border: 1px solid var(--border); }
  .btn-set { background: #78350f; color: var(--accent); }
  .btn-fan { background: #1e3a5f; color: var(--blue); }

  /* Status strip */
  .status-strip {
    margin-top: 12px;
    width: 100%;
    max-width: 480px;
    font-size: 10px;
    letter-spacing: .06em;
    color: var(--muted);
    text-align: center;
  }
  
  #ipAddr {
  display: inline-block;
  margin-top: 4px;
  font-size: 13px;   /* increase this if you want bigger */
  font-weight: 600;
  color: var(--blue);
}

  #mcuTemp {
  display: inline-block;
  margin-top: 4px;
  font-size: 13px;   /* increase this if you want bigger */
  font-weight: 600;
  color: var(--red);

#ipAddr a {
  color: var(--blue);
  text-decoration: none;
}

#ipAddr a:hover {
  text-decoration: underline;
}
  .dot {
    display: inline-block;
    width: 6px; height: 6px;
    border-radius: 50%;
    margin-right: 5px;
    background: var(--green);
    animation: pulse 2s infinite;
  }
  .dot.stale { background: var(--red); animation: none; }
  @keyframes pulse {
    0%,100%{ opacity:1; } 50%{ opacity:.4; }
  }
</style>
</head>
<body>

<h1>&#9632; Heater Chamber</h1>

<div class="grid">

  <!-- Temperature gauge -->
  <div class="card">
    <div class="label">Chamber temp</div>
    <div class="gauge-wrap">
      <svg class="arc-svg" width="120" height="72" viewBox="-10 0 120 72">
        <path class="arc-track" d="M5,65 A55,55 0 0,1 95,65"/>
        <path class="arc-fill" id="tempArc" d="M5,65 A55,55 0 0,1 95,65"
              stroke="#f59e0b"
              stroke-dasharray="0 173"/>
        <text class="arc-text" id="tempVal" x="50" y="58"
              text-anchor="middle" font-size="22">--</text>
        <text class="arc-sub" x="50" y="70"
              text-anchor="middle" font-size="9">°C</text>
      </svg>
    </div>
  </div>

  <!-- Humidity -->
  <div class="card">
    <div class="label">Humidity</div>
    <div class="gauge-wrap">
      <svg class="arc-svg" width="120" height="72" viewBox="-10 0 120 72">
        <path class="arc-track" d="M5,65 A55,55 0 0,1 95,65"/>
        <path class="arc-fill" id="humArc" d="M5,65 A55,55 0 0,1 95,65"
              stroke="#3b82f6"
              stroke-dasharray="0 173"/>
        <text class="arc-text" id="humVal" x="50" y="58"
              text-anchor="middle" font-size="22">--</text>
        <text class="arc-sub" x="50" y="70"
              text-anchor="middle" font-size="9">%RH</text>
      </svg>
    </div>
  </div>

  <!-- Setpoint -->
  <div class="card">
    <div class="label">Setpoint</div>
    <div class="value" id="spVal">--<span class="unit">°C</span></div>
    <div style="margin-top:10px">
      <div class="label" style="margin-top:8px">PID output</div>
      <div style="font-size:20px;font-weight:600;color:var(--accent)" id="pidVal">--%</div>
    </div>
  </div>

  <!-- Fan -->
  <div class="card">
    <div class="label">Fan speed</div>
    <div class="fan-pct" id="fanPct">--%</div>
    <div class="fan-bar-bg">
      <div class="fan-bar-fill" id="fanBar" style="width:0%"></div>
    </div>
    <div style="margin-top:6px;font-size:10px;color:var(--muted)" id="fanRaw">-- / 255</div>
  </div>

  <!-- Heater state -->
  <div class="card">
    <div class="label">Heater</div>
    <div id="heaterBadge" class="badge off">OFF</div>
    <div style="margin-top:12px">
      <div class="label">Safety</div>
      <div id="safetyBadge" class="badge on">OK</div>
    </div>
  </div>
  <!-- Fault -->
  <div id="faultBanner" style="
    display: none;
    grid-column: 1 / -1;
    background: #450a0a;
    color: #ef4444;
    border: 1px solid #7f1d1d;
    border-radius: 8px;
    padding: 10px 14px;
    font-size: 11px;
    letter-spacing: .06em;
    text-transform: uppercase;
    font-weight: 600;">
    &#9888; Sensor fault — check I2C wiring (SDA: GPIO8, SCL: GPIO9)
</div>

  <!-- Controls -->
  <div class="card wide controls">
    <div class="label">Controls</div>

    <div class="row">
      <button class="btn-on"  onclick="heater('on')">Heater ON</button>
      <button class="btn-off" onclick="heater('off')">Heater OFF</button>
    </div>

    <div class="row">
      <input type="number" id="tempInput" placeholder="Target °C" min="20" max="80" step="1">
      <button class="btn-set" onclick="setTemp()">Set Temp</button>
    </div>

    <div class="row">
      <input type="number" id="fanInput" placeholder="Fan 0–255" min="0" max="255" step="1">
      <button class="btn-fan" onclick="setFan()">Set Fan</button>
    </div>
  </div>

</div>

<div class="status-strip">
  <span class="dot" id="dot"></span>
  <span id="lastUpdate">connecting...</span>
  <br>
  <span id="ipAddr">--</span>
  <br>
  <span id="mcuTemp">esp32 temp: --</span>
  <br>
  <span id="fwVer">v--</span>
</div>

<script>
const ARC_LEN = 173;

function setArc(pct) {
  const fill = Math.max(0, Math.min(1, pct));
  const el = document.getElementById('tempArc');
  el.setAttribute('stroke-dasharray', `${fill * ARC_LEN} ${ARC_LEN}`);
  el.setAttribute('stroke', fill > .75 ? '#ef4444' : fill > .4 ? '#f59e0b' : '#3b82f6');
}
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
void loop() 
{
    server.handleClient();

#ifdef WEB_OTA
    ota_server.handleClient();
#endif 
    
    now = millis();

    if (now - lastSensor >= 1000) {
        lastSensor = now;
        readSensor();
       
        checkSafety(currentTemp);
    }

    if (heaterEnabled && !safetyTripped && (now - lastPid >= 500)) {
        lastPid   = now;
        pidOutput = pid.compute(currentTemp);
        hc.setPower(pidOutput);
        // Auto fan scales 55-255 with heater power
        // calibrated for the fan to actually start spinning at around 25% power, and be at full blast at 100% power
        fan_speed = (uint8_t)(55 + (255 - 55) * pidOutput);
        applyFanSpeed(fan_speed);
    }

    hc.update();

    if (now - lastOled >= 500) {
        lastOled = now;
        #ifdef DEBUG
        Serial.println(statusJson());
        Serial.flush();
        #endif
        d->update(currentTemp, currentHumidity, pid.getSetpoint(),
          heaterEnabled, fan_speed, pidOutput, sensorFault || highTempFault);
    }

    //update mcu temp every 1 minute only
    if (now - last_mcu_temp >= 1000*60) {
      last_mcu_temp = now;
      esp_err_t err = temperature_sensor_get_celsius(temp_sensor, &mcu_temp);
      #ifdef DEBUG
      if (err == ESP_OK) {
        Serial.printf("MCU Temperature: %.2f °C\r\n", mcu_temp);
      } else {
        Serial.println("Failed to read temperature");
      }
      #endif
    }
}

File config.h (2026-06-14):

#pragma once 

#define FW_VERSION "1.0.0"

// Pins (ESP32-C3 Super Mini) ────────────────────────────────────────────────
#define HEATER_PIN         3 // On/Off -> Heater
#define FAN_PWM_PIN     10   // PWM out -> MOSFET gate (LEDC)

// Fan LEDC
#define FAN_FREQ_HZ     25000
#define FAN_RESOLUTION  8       // 0–255

// Safety
#define MAX_TEMP_C      65.0f
#define DEFAULT_TARGET  50.0f
#define HEATER_CYCLE_MS    2000

// PID tuning; tune this based on heater and fan.
#define PID_KP  0.08f
#define PID_KI  0.015f
#define PID_KD  0.005f

// SHT3x
#define I2C_SDA     8
#define I2C_SCL     9

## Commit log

2026-06-14 Add the initial working commit
    [ESP32-C3_SUPERMINI_SMD.step, SHT30-Purple Straight Pins.step, heater.kicad_pcb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]
2026-06-21 Add first version of esp32c3 enclosure
    [SSD1306_OLED_Display(128x64).step]
